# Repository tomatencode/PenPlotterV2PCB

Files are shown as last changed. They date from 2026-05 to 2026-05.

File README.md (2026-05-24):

# Pen Plotter Controller Board

Eine selbst entworfene PCB-Steuerplatine für einen DIY Pen Plotter, entwickelt in KiCad. Die Platine steuert zwei Schrittmotoren für die XY-Bewegung, einen Servo für den Stifthub und übernimmt Benutzerführung sowie Energiemanagement vollständig auf einer einzigen Platine.

## Funktionen

- **ESP32** – Haupt-Mikrocontroller (Breakout aufgelötet) für Bewegungssteuerung und Logik
- **2× TMC2209** – Schrittmotortreiber (Breakouts aufgelötet) mit UART-Konfiguration, stealthChop und stallGuard
- **SG90 Servo** – Stift-Auf/Ab-Mechanismus
- **I2C LCD-Display** – Angeschlossen über Steckverbinder
- **Drehgeber** – Manuelle Steuerung und Menünavigation über Steckverbinder
- **Buzzer** – Akustisches Feedback
- **5V Buck Converter** – (Breakout aufgelötet) Erzeugt die interne 5V-Versorgungsschiene aus 24V
- **24V DC-Eingang** – Versorgung über externen Transformator (DC-Hohlbuchse)

## Stromversorgungsarchitektur

| Schiene | Quelle | Verbraucher |
|---|---|---|
| 24 V | Externer Transformator (DC-Buchse) | TMC2209 Motorspannung |
| 5 V | Buck Converter Breakout | ESP32, Servo, Buzzer, LCD |
| 3,3 V | Interner LDO des ESP32 | TMC2209 Logikspannung, Drehgeber |

## Platinenübersicht

### Schaltplan
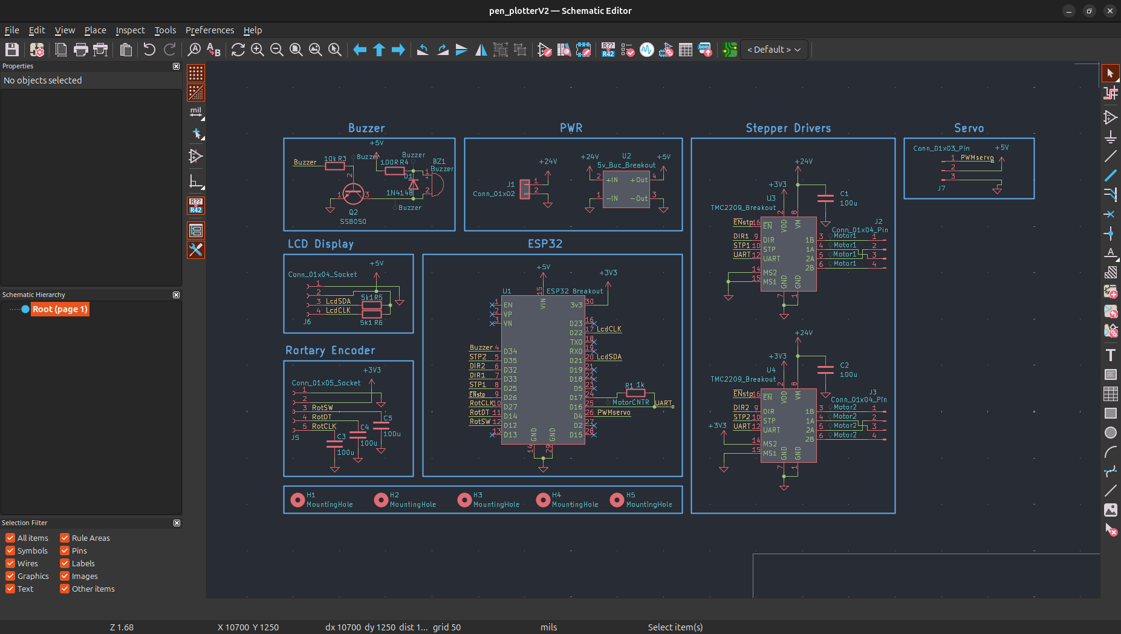
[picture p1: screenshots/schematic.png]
Schaltplan


### PCB-Layout
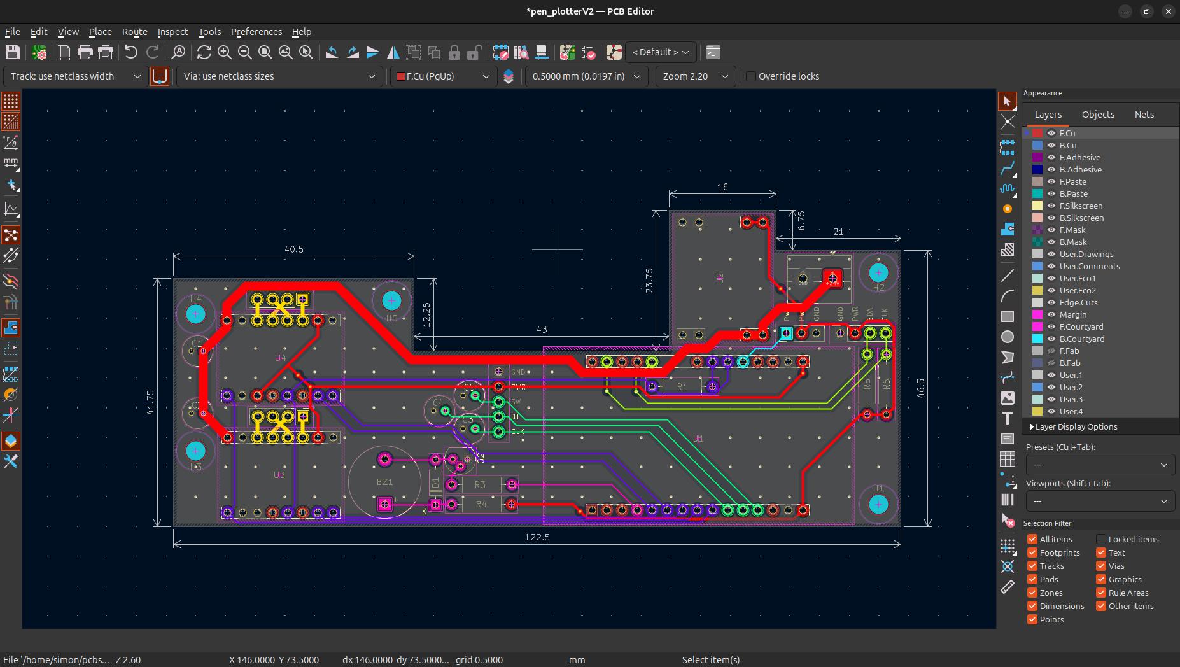
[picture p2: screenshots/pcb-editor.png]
PCB-Layout


### 3D-Ansicht
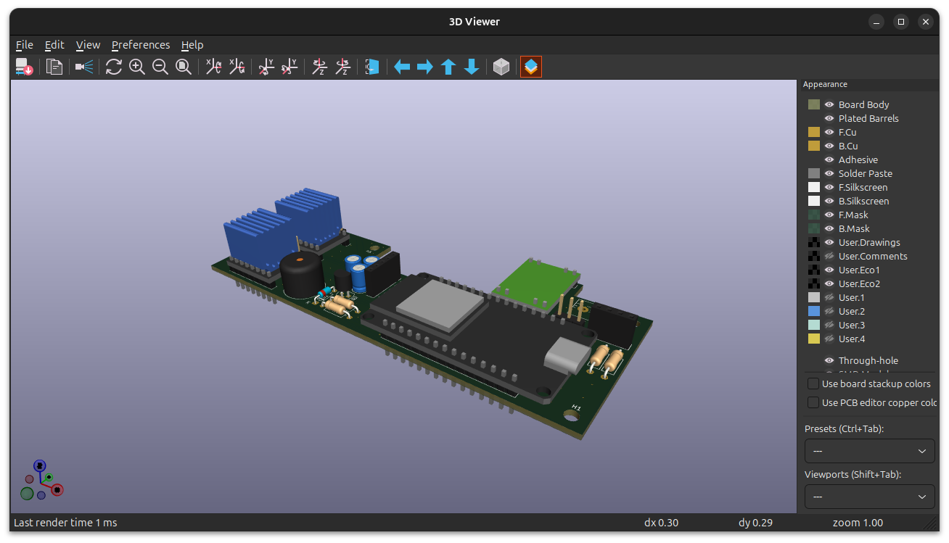
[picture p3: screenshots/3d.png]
3D-Ansicht


## Entwickelt mit

- [KiCad](https://www.kicad.org/) – Schaltplan und PCB-Layout

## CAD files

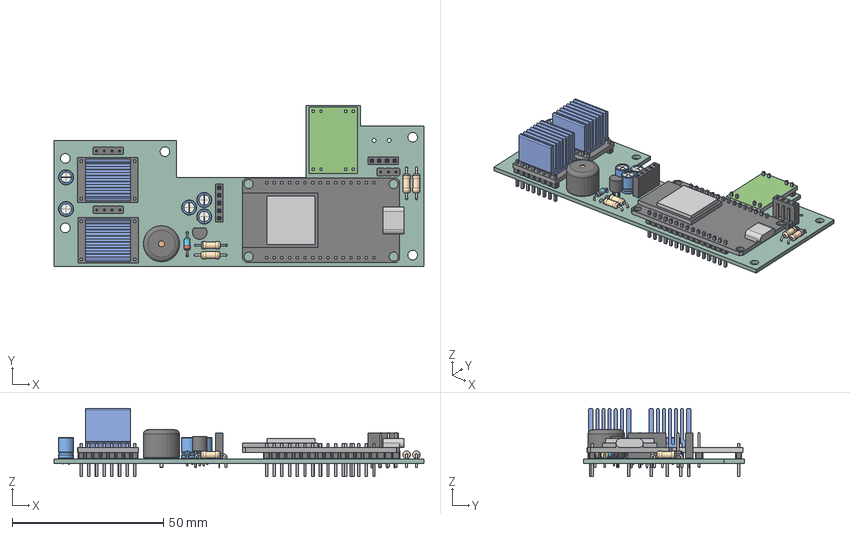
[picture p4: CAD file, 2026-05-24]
pen_plotter_v2_pcb.step
122.5 x 53.2 x 22.6 mm
R_Axial_DIN0207_L63mm_D25mm_P1016mm_Horizontal x 5
D_DO-35_SOD27_P7.62mm_Horizontal
C_Radial_D50mm_H70mm_P200mm x 5
PinHeader_1x04_P254mm_Vertical x 2
5V_Buc_Breakout
esp32
PinHeader_1x03_P254mm_Vertical
TMC2209 x 2
PinSocket_1x04_P2.54mm_Vertical
Buzzer_12x95RM76
TO-92_Narrow
PinSocket_1x05_P2.54mm_Vertical
pen_plotterV2_PCB

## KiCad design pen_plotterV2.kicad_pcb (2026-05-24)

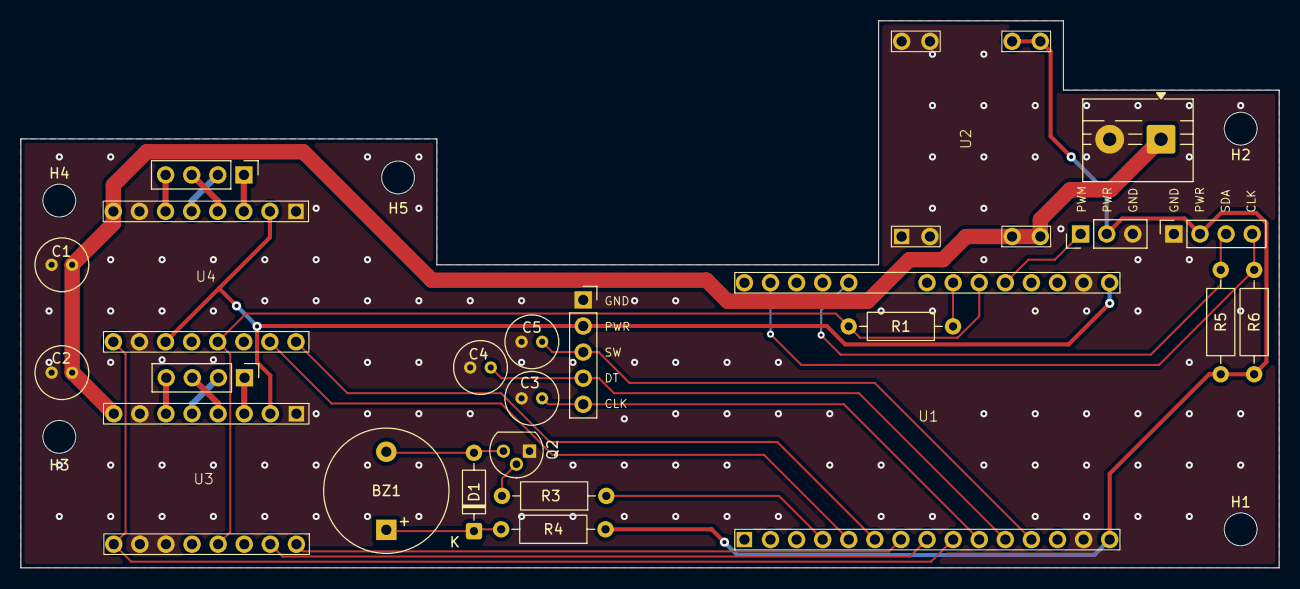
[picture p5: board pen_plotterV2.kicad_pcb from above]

Board: 2 copper layers, 122.5 x 53.2 mm, 28 parts (0 on the bottom side), 29 nets.

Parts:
BZ1: Buzzer; Buzzer_12x9.5RM7.6
C1, C2, C3, C4, C5: 100u; C_Radial_D5.0mm_H7.0mm_P2.00mm
D1: 1N4148; D_DO-35_SOD27_P7.62mm_Horizontal
H1, H2, H3, H4, H5: MountingHole; MountingHole_3.2mm_M3
J1: Conn_01x02; TerminalBlock_MaiXu_MX126-5.0-02P_1x02_P5.00mm
J2, J3: Conn_01x04_Pin; PinHeader_1x04_P2.54mm_Vertical
J5: Conn_01x05_Socket; PinSocket_1x05_P2.54mm_Vertical
J6: Conn_01x04_Socket; PinSocket_1x04_P2.54mm_Vertical
J7: Conn_01x03_Pin; PinHeader_1x03_P2.54mm_Vertical
Q2: SS8050; TO-92
R1: 1k; R_Axial_DIN0207_L6.3mm_D2.5mm_P10.16mm_Horizontal
R3: 10k; R_Axial_DIN0207_L6.3mm_D2.5mm_P10.16mm_Horizontal
R4: 100R; R_Axial_DIN0207_L6.3mm_D2.5mm_P10.16mm_Horizontal
R5, R6: 5k1; R_Axial_DIN0207_L6.3mm_D2.5mm_P10.16mm_Horizontal
U1: ESP32 Breakout; ESP32 Bev Board
U2: 5v_Buc_Breakout; 5V Buc Breakout
U3, U4: TMC2209_Breakout; TMC2209 Breakout

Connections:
+3V3: J5.2, U1.30 (3v3), U3.2 (VDD), U4.2 (VDD), U4.14 (MS2)
+5V: J6.2, J7.2, R4.1, R5.1, R6.2, U1.15 (VIN), U2.4 (+Out)
+24V: C1.1, C2.1, J1.1, U2.2 (+IN), U3.8 (VM), U4.8 (VM)
/Buzzer: R3.1, U1.4 (D34)
/DIR1: U1.7 (D33), U3.9 (DIR)
/DIR2: U1.6 (D32), U4.9 (DIR)
/LcdCLK: J6.4, R6.1, U1.17 (D22)
/LcdSDA: J6.3, R5.2, U1.20 (D21)
/PWMservo: J7.1, U1.26 (D4)
/RotCLK: C3.1, J5.5, U1.10 (D27)
/RotDT: C4.1, J5.4, U1.11 (D14)
/RotSW: C5.1, J5.3, U1.12 (D12)
/STP1: U1.8 (D25), U3.10 (STP)
/STP2: U1.5 (D35), U4.10 (STP)
/UART: R1.2, U1.25 (D16), U3.12 (UART), U4.12 (UART)
/~ENstp: U1.9 (D26), U3.16 (~EN), U4.16 (~EN)
GND: C1.2, C2.2, C3.2, C4.2, C5.2, J1.2, J5.1, J6.1, J7.3, Q2.1 (E), U1.14 (GND), U1.29 (GND), U2.1 (-IN), U2.3 (-Out), U3.1 (GND), U3.7 (GND), U3.14 (MS2), U3.15 (MS1), U4.1 (GND), U4.7 (GND), U4.15 (MS1)
unnamed: BZ1.1 (+), D1.1 (K), R4.2
unnamed: BZ1.2 (-), D1.2 (A), Q2.3 (C)
unnamed: J2.1, U3.3 (1B)
unnamed: J2.2, U3.5 (2A)
unnamed: J2.3, U3.4 (1A)
unnamed: J2.4, U3.6 (2B)
unnamed: J3.1, U4.3 (1B)
unnamed: J3.2, U4.5 (2A)
unnamed: J3.3, U4.4 (1A)
unnamed: J3.4, U4.6 (2B)
unnamed: Q2.2 (B), R3.2
unnamed: R1.1, U1.24 (D17)
